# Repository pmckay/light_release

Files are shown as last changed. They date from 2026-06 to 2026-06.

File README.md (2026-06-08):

# light_release

This repository contains all of the documentation, CAD files, and code necessary to create your own underwater light release system. For brief overview of how to turn on, run, and retrieve data from the sensor, look to "LightRelease_UserManual" pdf. 

light_release

Parts list:
 - 12 inch lenght of 3inch diameter PVC tubing
    - https://www.amazon.com/CKVIHAV-Industrial-Greenhouse-Workshop-Furniture/dp/B0G7W7V1F6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
 - flat cap for 3ich diameter PVC tubing
     - https://www.amazon.com/Zernmiarder-Round-Plugs-Furniture-Fitting/dp/B0D548LVB5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
 - 3inch PVC threaded male coupling
    - https://www.amazon.com/Canplas-192873-Adapter-3-Inch-White/dp/B00CDSZ052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
 - 3 inch PVC threaded female cap
    - https://www.amazon.com/Spears-Pipe-Fitting-Schedule-Female/dp/B008I4ERPE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
 - Marine Sealant
    - https://www.amazon.com/3M-5200FC-Marine-Adhesive-Sealant/dp/B003E1ULRE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
 - Raspberry Pi Pico W2 microcontroller
    - https://www.adafruit.com/product/6315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
 - TSL2591 light sensor
    - https://www.adafruit.com/product/1980
 - Pressure sensor
    - https://www.sparkfun.com/sparkfun-pressure-sensor-breakout-ms5803-14ba.html
 - DS3231 clock
    - https://www.amazon.com/DS3231-AT24C32-Module-Memory-Replace/dp/B09LLMYBM1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
 - Electromagnet (200 ft spool of 24 AGW magnet wire)
    - https://www.amazon.com/BNTECHGO-AWG-Magnet-Wire-Transformers/dp/B01NBM0MB5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
 - Relay 
    - https://www.amazon.com/Channel-Optocoupler-Isolated-Control-Arduino/dp/B07XGZSYJV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
 - 12v Battery Pack (1.5v AA x 8)
    - https://www.amazon.com/VWEICYY-Battery-Holder-housing-Leads/dp/B0DZWWJ7Z9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
 - 12v to 5v Divider
    - https://www.amazon.com/24V-5V-Converter-Regulator-Transformer/dp/B0BW3SRK77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

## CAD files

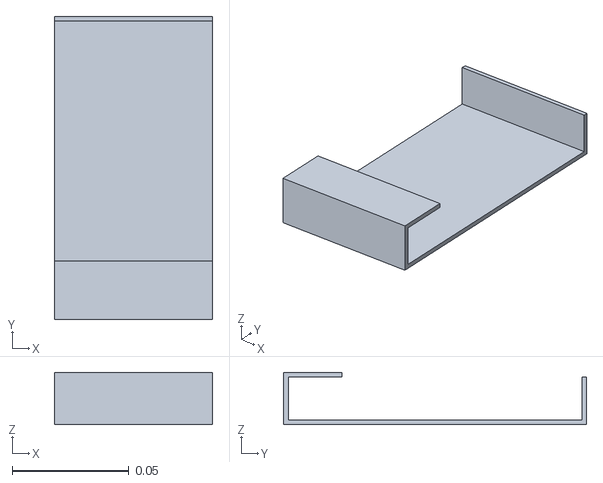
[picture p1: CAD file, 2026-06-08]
circuitry holder (1).stl
0.068 x 0.13 x 0.0225

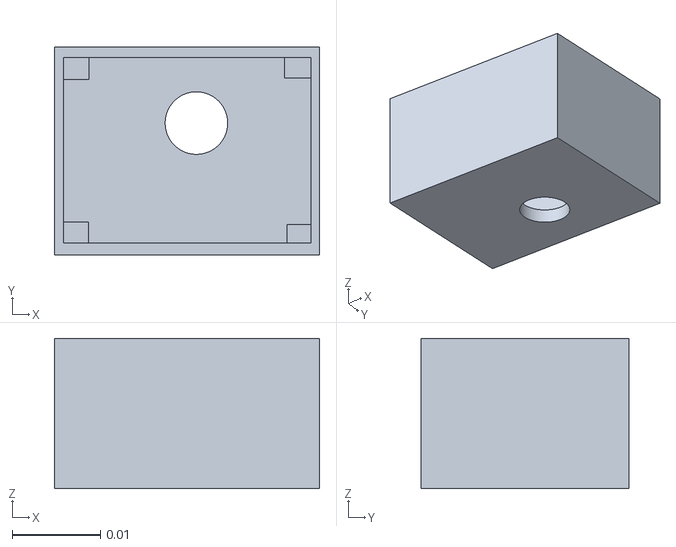
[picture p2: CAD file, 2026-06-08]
lightesensor (1).stl
0.03 x 0.0235 x 0.017

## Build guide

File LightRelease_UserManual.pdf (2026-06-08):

Light Release User Manual: Before turning on:

- Plug into microcontroller with python IDE such as Thonny
- Insure main.py and light_release_final.py are installed on the breadboard
- Delete any pre-existing “deployment.csv” files
- Set deployment time equal to how long you want the sensor to be underwater for
- Double check that all connections are plugged in correctly
- Make sure switch on breadboard is in the on position
Pre-deployment:
- Turn on battery pack
- Put internal assembly into the housing
- Put electromagnet at the bottom of the housing
- Screw bottom cap into place tightly
Deployment:
- Place package onto mooring, securing the magnet in place
- Gently lower mooring to seabed
- Set reminder for surfacing time
Retrieval:
- After package has surfaced, collect it and dry it off
- Unscrew bottom cap
- Take out electromagnet and circuit
- Switch off battery
- Plug into microcontroller and download “deployment.csv”

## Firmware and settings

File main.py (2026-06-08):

import release_system_final
from machine import Pin
from time import sleep

# define input pins
pin18 = Pin(18, Pin.OUT)
pin19 = Pin(19, Pin.IN)
pin20 = Pin(20, Pin.OUT)

pin18.value(0)
pin20.value(1)

led = Pin("LED", Pin.OUT)

if pin19.value() == 1:
    print("System started.")
    led.on()
    sleep(3)
    led.off()
    release_system_final.release_system()
else:
    print("Failed to start the system. ")

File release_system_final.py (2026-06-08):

from machine import I2C, SoftI2C, Pin
from time import sleep_ms, ticks_ms, ticks_diff
import urtc
import TSL2591


# the release system: controlling the instrument and supports data documenting
def release_system(): 

    # Define pins and sensors

    # Real Time Clock (DS3231)
    i2c_rtc = I2C(0, sda=(12), scl=(13), freq=400000)
    rtc = urtc.DS3231(i2c_rtc)

    # Light Sensor (TSL2591)
    i2c_light = I2C(1, sda=Pin(2), scl=Pin(3), freq=100000)
    light_sensor = TSL2591.TSL2591(i2c_light)
    # Set the gain to low 
    light_sensor.gain = TSL2591.GAIN_LOW

    relay = Pin(15, Pin.OUT)
    # defalt: not released 
    relay.value(0)
    
    start = ticks_ms()
    # duration = 60 * 60 * 1000 # 1 hour, modify if needed
    duration = 1000 * 60 * 15 # 15 minutes (for testing)
    min_lux = 2000
    max_lux = 10000
    measurements = open("measurements.csv", "a")
    measurements.write("datetime,lux,relay \n")
    measurements.flush()

    while ticks_diff(ticks_ms(), start) < duration:
        lux = light_sensor.lux
        if lux >= min_lux and lux < max_lux:
            relay.value(1)
            print(relay.value(), "released")
            sleep_ms(5000)
            relay.value(0)
            print("relay set to 0")
        else:
            relay.value(0)
            sleep_ms(5000)
            
        print("lux:", lux, "relay:", relay.value())
        documentToFile(rtc, measurements, lux, relay)
        sleep_ms(5000)

    minutes = ticks_diff(ticks_ms(), start) / (1000 * 60)
    print(f"The instrument has been deployed for {minutes:.2f} minute(s).")
    relay.value(1)
    sleep_ms(5000)
    documentToFile(rtc, measurements, lux, relay)
    relay.value(0)
    print("relay_value: ", relay.value())
#     while True:
#         documentToFile(rtc, measurements, lux, relay)
#         sleep_ms(10000)
    measurements.flush()
    measurements.close()



# A helper function that formats the text to be written into the data file
def documentToFile(rtc, fileName, lux, relay):
    now = rtc.datetime()
    timestamp = "{:04d}/{:02d}/{:02d} {:02d}:{:02d}:{:02d}".format(now[0], now[1], now[2], now[4], now[5], now[6])
    fileName.write(timestamp + "," + str(lux) + "," + str(relay.value()) + "\n")
#     measurements.flush()
